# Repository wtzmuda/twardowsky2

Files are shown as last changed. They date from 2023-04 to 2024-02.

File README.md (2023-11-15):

<div align="center">
    

  <h3 align="center"><strong>Twardowsky 2</strong><br/>SKA Rocketry Division</h3>

  <p align="center">
      <a href="https://wutwaw-my.sharepoint.com/:f:/g/personal/01171578_pw_edu_pl/EmQTOotIGo9FmwbVG2P4nIABuc8mOalsro14rPONq2J7Fg" target="_blank"><strong>See project's sharepoint »</strong></a>
    <br />
    <br />
    <a href="https://gitlab.com/sekcja-rakietowa-ska/twardowsky2/-/commits/main?ref_type=heads">Commits</a>
    ·
    <a href="https://gitlab.com/sekcja-rakietowa-ska/twardowsky2/-/branches">Branches</a>
    ·
    <a href="https://gitlab.com/sekcja-rakietowa-ska/twardowsky2/-/issues">Issues</a>
  </p>
</div>

## Getting started

Run `git clone https://gitlab.com/sekcja-rakietowa-ska/twardowsky2.git`

*Do not have a git? Ask our coordinator for help!*

Remember to run `RunThisWhenYouClone.sh` command after cloning this repository. This makes sure that Your commit messages are correctly formatted and up to our standards.

Also we have strict messaging and naming standards. Please read *Git messages standards* section .

## Project description

Twardowsky 2 is a hybrid-engine rocket with ability to carry payload in the form of cubesat experiments. It is being developed by the Student's Space Association's Rocketry Division on Warsaw University of Technology.

## Git messages standards

Correct formmat for our messages is:
`[TAG] commit-message` or `#issue-number commit-message`

Where: 
* **TAG** - Points out which system does this commit concern? 
* **#issue-number** - Points out which issue does this commit concern?
* **commit-message** - Is a description of the changes. Remember it is not ught to be short. It should be as descriptive and precise as it can be.

*Example: [PLD] Changed strings on payload's module.*

### Commit tags
Below are listed possible tags with it's description:

* **[TWR]** - Twardowsky - concerning whole project (like req / risk changes), can be used with other tags to specify but there are files that concern the whole project
* **[GSG]** - Ground segment - concerning GSE, mission control, procedures for launches etc.
* **[SPC]** - Spacecraft - technical changes to TWR assembly
* **[NSC]** - Nosecone
* **[PLD]** - Payload
* **[REC]** - Recovery
* **[PRP]** - Propulsion
* **[AVI]** - Avionics (I know seems kinda redundant since we have NSC but there are SE aspects that could concern only Avionics)
* **[CTS]** - COTS/standardized elements changes
* **[MNG]** - Management / organizational
* **[DOC]** - Documentation
* **[SYS]** - Systems engineering
* **[OTH]** - doesn't fit any of the above (might suggest that there's need for new tag)

*Feel free to contact Your coordinator if You have any doubts or remarks.*

### Commit issues
Below are listed possible issues with it's description: 

* **#1** - Construction/mechanical/technical
* **#2** - Electronics/software/firmware
* **#3** - Documentation
* **#4** - Systems Engineering
* **#5** - Analysis
* **#6** - Management/administration
* **#7** - Finances/orders
* **#8** - Competitions
* **#9** - Research
* **#10** - Other

## Contact

1. **Project coordinator** - Eliza Łapińska - yes sir#1909

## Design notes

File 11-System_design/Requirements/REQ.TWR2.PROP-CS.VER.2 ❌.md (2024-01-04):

---
Title: REQ.TWR2.PROP-CS.VER.2
Status: conflict
System: TWR2.PROP-CS
Class: Requirement
Conflicting With: 11-System_design/Requirements/REQ.TWR2.PROP-CS.VER.1 ❌.md
---

## Description

During leakage test conditions (8 bar for 180 minutes) the maximum allowable pressure drop is less than 0.5 bar

## Source

TWR 2 propulsion

NO - [The requirements do not conflict because they pertain to different testing conditions and pressures. The first requirement refers to a leakage test at 8 bar, the second to a pressure proof test at 90 bar, and the third to a filling and pressurization procedure at a max of 60 bar. Each requirement has the same allowable pressure drop of less than 0.5 bar, but this value is not in conflict across the different conditions and pressures.]YES - There is a conflict between the given leakage test condition and the proof pressure test conditions as well as the condition regarding the tank pressurization. The pressure for the proof test condition and tank pressurization is significantly higher than the given leakage test condition. This may result in different maximum allowable pressure drops, leading to potential conflicts - [[11-System_design/Requirements/REQ.TWR2.PROP-CS.VER.1 ❌.md]], [[Requirements/REQ.TWR2.AVI.DES.33  ❌.md]]. To resolve the issue, it would be better to harmonize and clearly define the pressure conditions and allowable pressure drops across all tests.YES - The first and third requirements specified different pressure and time conditions for a test, causing a conflict - [[11-System_design/Requirements/REQ.TWR2.PROP-CS.VER.1 ❌.md]], [[undefined]]. A better way to resolve it would be to standardize the conditions for the pressure test and define it in one requirement.

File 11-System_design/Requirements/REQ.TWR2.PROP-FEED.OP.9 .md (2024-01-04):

---
Title: REQ.TWR2.PROP-FEED.OP.9
Status: in-review
System: TWR2.PROP-FEED
Class: Requirement
Conflicting With: 
---

## Description

Sealants of hydraulic systems shall allow to conduct the procedure of filling and pressurizing (max duration 90 minutes at max pressure 60 bar) with acceptable pressure drop of 0,5 bar 

## Source

TWR 2 propulsion/ REQ.TWR2.PROP.OP.6

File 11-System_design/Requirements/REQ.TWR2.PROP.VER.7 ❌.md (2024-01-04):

---
Title: REQ.TWR2.PROP.VER.7
Status: conflict
System: TWR2.PROP
Class: Requirement
Conflicting With: 11-System_design/Requirements/REQ.TWR2.PROP-CS.VER.2 .md
---

## Description

Pressure vessels shall be proof pressure tested successfully to 1.5 times the maximum expected operating pressure for no less than twice the maximum expected system working time, using the intended flight components. The maximum system working time is defined as the maximum uninterrupted time duration the vessel will remain pressurized during pre-launch, flight, and recovery operations. 

## Source

EuRoC/ IREC Design, Test, & Evaluation Guide 2023 V1.3/ 6.25.1., 6.25.2.- Bartosz Hyży

undefined

undefined

undefinedYES - The given requirement states that pressure vessels should be tested successfully to 1.5 times the maximum expected pressure for a duration that is twice the maximum expected system working time. However, in REQ.TWR2.PROP-CS.VER.2 the condition for leakage tests is given as 8 bar for 180 minutes. There may be a conflict if the maximum expected operating pressure multiplied by 1.5 or the maximum expected system working time doubled does not match the 8 bar for 180 minutes condition. Depending on the actual maximum expected operating pressure and system working time, these conditions might not align. - [[REQ.TWR2.PROP-CS.VER.2 ]]

A possible resolution can be standardizing the testing conditions across all documents, or explaining how both these tests have different objectives and should be executed separately.YES - The given requirement demands a proof pressure test at 1.5 times the maximum expected operating pressure and for a time duration twice that of the maximum expected system working time. Yet, the requirement to compare specifies testing for leakage conditions at a defined pressure (8 bar) for 180 minutes. These two testing conditions may not be the same and thus, a conflict arises. A possible solution would be to harmonize the testing conditions such that the proof pressure test and the leakage test can both be conducted without contradicting each other. - [[REQ.TWR2.PROP-CS.VER.2 ]]

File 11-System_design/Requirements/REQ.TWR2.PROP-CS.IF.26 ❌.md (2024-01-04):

---
Title: REQ.TWR2.PROP-CS.IF.26
Status: conflict
System: TWR2.PROP-CS
Class: Requirement
Conflicting With: 11-System_design/Requirements/REQ.TWR2.PROP-CS.CONF.19 .md
---

## Description

It shall be possible to install swirl injector or showerhead injector in the same plug assembly

## Source

TWR 2 propulsion

undefined

undefined

undefined

undefined

undefined

undefinedYES - There are potential conflicts between the requirement of having both a swirl injector or showerhead injector in the same plug assembly and the requirement that an igniter be located in the plug assembly. Depending on the arrangement, there might not be enough space in the assembly for both an injector and an igniter. Also, the requirement concerning the showerhead injector hole diameter assumes a specific design that may or may not be compatible with the use of an igniter or swirl injector. [[11-System_design/Requirements/REQ.TWR2.PROP-CS.CONF.19 .md]] [[11-System_design/Requirements/REQ.TWR2.PROP-CS.PHYS.22 .md]]

A possible solution could involve designing the plug assembly to accommodate different configurations or clarify the design constraints of the showerhead injector and swirl injector so they can coexist with the igniter. Another possibility could be to revise the requirement about the igniter's location.YES - The requirement specifies two types of injectors to be installed in the plug assembly, however, there is another requirement for the igniter to be located in the same assembly. This can create a space conflict within the plug assembly. It needs to be ensured that the igniter and either of the injectors can be fitted into the plug assembly without any functional obstruction - [[11-System_design/Requirements/REQ.TWR2.PROP-CS.CONF.19 .md]]

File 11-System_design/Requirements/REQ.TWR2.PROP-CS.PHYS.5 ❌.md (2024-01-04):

---
Title: REQ.TWR2.PROP-CS.PHYS.5
Status: conflict
System: TWR2.PROP-CS
Class: Requirement
Conflicting With: 11-System_design/Requirements/REQ.TWR2.PROP-CS.PHYS.4 .md
---

## Description

Combustion chamber insulation shall allow the combustion chamber hardware to withstand temperature loads (3300K) for the time of work (10s)

## Source

TWR 2 propulsion

NO - [There doesn't appear to be any conflicts between these requirements. The given requirement pertains to temperature loads and duration, the first requirement to compare speaks to mechanical loads, the second one refers to pressure and duration, and the third one addresses testing. These specifications are dealing with different aspects of the combustion chamber's functionality and should not conflict unless specific material, design or procedures counteract.]YES - The time of work given in the first compared requirement (20s) contradicts with the time of work given in the given requirement (10s). - [[11-System_design/Requirements/REQ.TWR2.PROP-CS.PHYS.4 .md]] 

One possible way to resolve this issue might be adjusting one of the time frames to match with the other one after considering engineering constraints and the overall mission goals.YES - The given requirement and the first compared requirement may conflict. The given requirement suggests the chamber will operate at 3300K for 10 seconds, but the compared requirement states that the chamber needs to withstand a pressure of 45 bar for 20 seconds. If the chamber can only endure high temperatures for half of the required pressure duration, this could result in damage or failure. - [[11-System_design/Requirements/REQ.TWR2.PROP-CS.PHYS.4 .md]]

To resolve the issue, we should aim to improve the insulation of the combustion chamber or redesign it so that the temperature can be maintained for a longer duration. This might involve using different materials for insulation or altering the combustion chamber's design to dissipate heat more effectively.

[[11-System_design/Requirements/REQ.TWR2.PROP-CS.PHYS.4 .md]] should be updated to make sure both conditions (temperature and pressure) can be sustained for the same duration.

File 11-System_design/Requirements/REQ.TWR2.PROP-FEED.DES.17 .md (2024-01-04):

---
Title: REQ.TWR2.PROP-FEED.DES.17
Status: in-review
System: TWR2.PROP-FEED
Class: Requirement
Conflicting With: 
---

## Description

Main valve shall incorporate at least two redundant pyrotechnic primes

## Source

TWR 2 propulsion

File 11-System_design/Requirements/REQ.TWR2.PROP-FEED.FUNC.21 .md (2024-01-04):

---
Title: REQ.TWR2.PROP-FEED.FUNC.21
Status: in-review
System: TWR2.PROP-FEED
Class: Requirement
Conflicting With: 
---

## Description

The venting system should ensure a reliable release of oxidizer outside the rocket structure in the event of launch abort

## Source

#REF!

undefined

undefined

undefined

undefined

undefined

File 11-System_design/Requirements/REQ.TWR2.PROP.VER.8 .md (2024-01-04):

---
Title: REQ.TWR2.PROP.VER.8
Status: in-review
System: TWR2.PROP
Class: Requirement
Conflicting With: 
---

## Description

Propulsion systems shall successfully complete an instrumented (chamber pressure and/or thrust), full scale (including system working time) static hot-fire test. The test shall be conducted under the most realistic settings possible. Test results from horizontal tests, using flight components, are less optimum, whereas test results from test benches (not using flight components) do not qualify. (TBD with EuRoC)

## Source

EuRoC

undefined

undefined

undefined

undefined

undefined

undefined

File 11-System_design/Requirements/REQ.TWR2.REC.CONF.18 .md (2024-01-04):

---
Title: REQ.TWR2.REC.CONF.18
Status: in-review
System: TWR2.REC
Class: Requirement
Conflicting With: 
---

## Description

All safety critical wiring shall implement a cable management solution (e.g., wire
ties, wiring, harnesses, cable raceways) which will prevent tangling and excessive
free movement of significant wiring/cable lengths due to expected launch loads.  Wiring shall be labeled or color-coded to allow easy determination of the subsystem
to which it is attached. 

## Source

Spaceport: IREC Design, Test, & Evaluation Guide 2023 V1.3/ 5.7.1. -Szymon Życiński

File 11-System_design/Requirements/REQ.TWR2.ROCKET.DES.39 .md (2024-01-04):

---
Title: REQ.TWR2.ROCKET.DES.39
Status: in-review
System: TWR2.ROCKET
Class: Requirement
Conflicting With: 
---

## Description

PVC (and similar low-temperature polymers), Public Missiles Ltd. (PML) Quantum Tube,
and stainless-steel shall not be used in any rocket airframe structure. PVC (and similar lowtemperature polymers), stainless steel, or other frangible materials shall not be used for a solid or hybrid propulsion system combustion chamber. 

## Source

 Spaceport: IREC Design, Test, & Evaluation Guide 2023 V1.3/ 8.3.- Bartosz Hyży

undefined

undefined

undefined

undefined

undefined

undefined

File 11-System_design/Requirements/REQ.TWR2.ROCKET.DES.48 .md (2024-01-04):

---
Title: REQ.TWR2.ROCKET.DES.48
Status: in-review
System: TWR2.ROCKET
Class: Requirement
Conflicting With: 
---

## Description

Airframe joints which implement "coupling tubes" should be designed such that the coupling tube extends no less than one body calibre (1D) on either side of the joint — measured from the separation plane. This rule applies both for “half” couplings (e.g., nosecone – body tube/coupling tube) as well as for “full” couplings (e.g., body tube – coupling tube – body tube)

## Source

EuRoC Design, Test & Evaluation Guide; Version 4.4

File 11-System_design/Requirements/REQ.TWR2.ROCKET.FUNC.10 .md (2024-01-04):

---
Title: REQ.TWR2.ROCKET.FUNC.10
Status: in-review
System: TWR2.ROCKET
Class: Requirement
Conflicting With: 
---

## Description

The rocket's subsystems shall have an ability to function independetly, their joints shall be standardized and they shoud be exchangeable.

## Source

Concept of Operation/ Eliza Łapińska

undefined

undefined

undefined

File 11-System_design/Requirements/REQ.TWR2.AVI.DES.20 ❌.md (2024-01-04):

---
Title: REQ.TWR2.AVI.DES.20
Status: conflict
System: TWR2.AVI
Class:
  - Requirement
ID: TWR2.AVI.REQ.TWR2.AVI.DES.20
Conflicting With: 11-System_design/Requirements/REQ.TWR2.AVI.DES.39 ❌.md
---

## Description
RF transmitter, receivers or transceivers are not allowed to be mounted externally. Any RF antenna should have either: "RF Window" for antennas mounted internally or at least two-sided antenna mounted externally to provide for full 360 coverage. [NOTE] Single antenna mounted on the rear-fin of a flight vehicle will be insufficient, since the exhaust flames are highly disruptive towards the RF signals

## Source

EuRoC Design, Test & Evaluation Guide; Version 4.6

# Conflict

YES - The conflict lies in the location of RF transmitters, receivers or transceivers, and antennas; the given requirement mandates no external mountings, whereas the requirement in comparison implies the possibility of such installations. - [[11-System_design/Requirements/REQ.TWR2.AVI.DES.39 ❌.md]] 
A possible resolution would be to agree upon fixed locations for the RF devices and the antennas, either internally with RF windows or externally considering the "360 deg" coverage rule.

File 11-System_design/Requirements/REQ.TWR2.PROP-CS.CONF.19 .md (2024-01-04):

---
Title: REQ.TWR2.PROP-CS.CONF.19
Status: in-review
System: TWR2.PROP-CS
Class: Requirement
Conflicting With: 
---

## Description

Igniter should be located in the plug assembly

## Source

TWR 2 propulsion

undefined

undefined

undefined

undefined

undefined

undefined

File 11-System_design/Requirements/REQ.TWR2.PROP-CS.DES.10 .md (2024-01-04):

---
Title: REQ.TWR2.PROP-CS.DES.10
Status: in-review
System: TWR2.PROP-CS
Class: Requirement
Conflicting With: 
---

## Description

Combustion chamber geometry shall allow stable work of engine (precombustion chamber)

## Source

TWR 2 propulsion

NO - [The requirements do not in-revision each other. The given requirement and others all deal with various aspects of the combustion chamber such as its functionality, ability to conduct tests, sealing under pressure, and integration with the rest of the rocket. None of these aspects are mutually exclusive or contradictory, which means all these requirements can be fulfilled without conflicting with each other.]

NO - All of the requirements listed are related to the quality, functionality, and compatibility of the combustion chamber. They should not conflict since each one addresses a different aspect of the design. Stable operation, integration with the rocket, and ability to undergo pressure tests do not inherently conflict.

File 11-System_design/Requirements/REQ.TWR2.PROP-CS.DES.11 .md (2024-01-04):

---
Title: REQ.TWR2.PROP-CS.DES.11
Status: in-review
System: TWR2.PROP-CS
Class: Requirement
Conflicting With: 
---

## Description

Combustion chamber geometry shall allow the Hot Fire test on Hefajstos test stand

## Source

TWR 2 propulsion

NO - [There is no direct conflict between the given requirement and the requirements to compare. The ability to conduct a Hot Fire test on a Hefajstos test stand does not inherently conflict with the needs for the combustion chamber to allow pressure and seal tests, to work stably, to be integrable with the rocket, or to withstand mechanical loads during flight. These requirements are all addressing different facets of the combustion chamber’s functionality and integrity. However, the satisfaction of all requirements would need to be validated empirically.]

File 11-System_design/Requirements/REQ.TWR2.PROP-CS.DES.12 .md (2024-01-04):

---
Title: REQ.TWR2.PROP-CS.DES.12
Status: in-review
System: TWR2.PROP-CS
Class: Requirement
Conflicting With: 
---

## Description

There shall be appropriate sealing elements placed to inhibit outer surface of grain

## Source

TWR 2 propulsion- Bartek Hyży

undefined

undefined

undefined

undefined

undefined

undefined

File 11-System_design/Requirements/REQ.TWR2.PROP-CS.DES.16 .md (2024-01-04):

---
Title: REQ.TWR2.PROP-CS.DES.16
Status: in-review
System: TWR2.PROP-CS
Class: Requirement
Conflicting With: 
---

## Description

 All teams shall use dual or dual-headed motor igniters for launch

## Source

Spaceport: IREC Design, Test, & Evaluation Guide 2023 V1.3/ 5.9.- Bartosz Hyży

undefined

NO - The requirement to compare is identical to the given requirement, therefore there are no in-revisions.

undefined

undefined

undefined

undefined

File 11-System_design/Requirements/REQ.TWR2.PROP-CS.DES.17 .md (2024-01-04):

---
Title: REQ.TWR2.PROP-CS.DES.17
Status: in-review
System: TWR2.PROP-CS
Class: Requirement
Conflicting With: 
---

## Description

Igniter's sealings shall be made from materials compatible with nitrous oxide

## Source

TWR 2 propulsion

NO - [All the compared requirements specify the materials to be compatible with nitrous oxide or corrosion-resistant, this does not conflict with the given requirement which also states the materials used should be compatible with nitrous oxide.]

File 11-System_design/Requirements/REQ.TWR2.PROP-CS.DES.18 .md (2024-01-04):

---
Title: REQ.TWR2.PROP-CS.DES.18
Status: in-review
System: TWR2.PROP-CS
Class: Requirement
Conflicting With: 
---

## Description

Igniter shall use black powder as the main propellant

## Source

TWR 2 propulsion

undefined

undefined

undefined

undefined

undefined

undefined

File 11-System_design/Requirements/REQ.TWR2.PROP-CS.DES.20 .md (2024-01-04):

---
Title: REQ.TWR2.PROP-CS.DES.20
Status: in-review
System: TWR2.PROP-CS
Class: Requirement
Conflicting With: 
---

## Description

Igniter shall be made from materials that are corrosion resistant or are corrosion protected

## Source

TWR 2 propulsion

NO - [The given requirement specifies that the igniter should be made from materials that are either corrosion-resistant or protected against corrosion. The other requirements state that the igniter body and sealings should be made from materials compatible with nitrous oxide and that the injection system elements should be corrosion-resistant. None of these requirements conflict with each other, because it's possible for a material to be both corrosion-resistant and compatible with nitrous oxide. Hence, there are no conflicts between these requirements.]

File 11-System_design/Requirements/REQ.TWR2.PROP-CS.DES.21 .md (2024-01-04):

---
Title: REQ.TWR2.PROP-CS.DES.21
Status: in-review
System: TWR2.PROP-CS
Class: Requirement
Conflicting With: 
---

## Description

Igniter body shall be made from materials compatible with nitrous oxide

## Source

TWR 2 propulsion

NO - [The given requirement states that the igniter body should be made from materials compatible with nitrous oxide. This is consistent with all the compared requirements, which either specifically mention nitrous oxide compatibility (the igniter sealings, injection system, and contact components) or suggest a condition (corrosion resistance/protection) that does not inherently conflict with nitrous oxide compatibility. Therefore, there are no conflicts between these requirements.]

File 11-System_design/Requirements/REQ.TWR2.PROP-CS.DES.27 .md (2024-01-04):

---
Title: REQ.TWR2.PROP-CS.DES.27
Status: in-review
System: TWR2.PROP-CS
Class: Requirement
Conflicting With: 
---

## Description

Injection system elements hall be made from materials compatible with nitrous oxide

## Source

TWR 2 propulsion

NO - [All the requirements state that the specific components of the system need to be compatible with nitrous oxide. Additionally, the requirement that injection system elements shall be made from corrosion resistant materials does not in-revision with the given requirement, as corrosion-resistant materials could still be compatible with nitrous oxide. Therefore, there is no conflict between the stated requirements.]

NO - [All requirements state that the materials used in the injection system should be compatible with nitrous oxide. There is another requirement that the materials should also be corrosion resistant. There is no conflict between these requirements, unless a material that is compatible with nitrous oxide is not corrosion resistant. However, this is not specified, so no conflict can be determined based on the information provided.]

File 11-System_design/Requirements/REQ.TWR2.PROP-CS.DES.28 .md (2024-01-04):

---
Title: REQ.TWR2.PROP-CS.DES.28
Status: in-review
System: TWR2.PROP-CS
Class: Requirement
Conflicting With: 
---

## Description

Injection system elements shall be made from corrosion resistant materials

## Source

TWR 2 propulsion

NO - [The materials for the injection system elements can be both corrosion resistant and compatible with nitrous oxide; these requirements are not mutually exclusive. Also, the second comparison requirement simply specifies that the igniter should be corrosion resistant or protected, which does not contradict the given requirement.]

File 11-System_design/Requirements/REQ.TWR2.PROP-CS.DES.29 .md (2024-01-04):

---
Title: REQ.TWR2.PROP-CS.DES.29
Status: in-review
System: TWR2.PROP-CS
Class: Requirement
Conflicting With: 
---

## Description

Materials of the sealings in injection system shall be compatible with nitrous oxide

## Source

TWR 2 propulsion

NO - [All requirements mandate that materials in contact with nitrous oxide, including sealings, be compatible with it. Therefore, there is no conflict among these requirements. All are in sync, working towards ensuring suitability and safety with nitrous oxide.]

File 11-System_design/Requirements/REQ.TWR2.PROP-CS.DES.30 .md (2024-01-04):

---
Title: REQ.TWR2.PROP-CS.DES.30
Status: in-review
System: TWR2.PROP-CS
Class: Requirement
Conflicting With: 
---

## Description

The nozzle geometry should allow usage of appropriate nozzle plug to gain the initial pressure of work (10 bar)

## Source

TWR 2 propulsion

undefined

undefined

undefined

undefined

undefined

undefined

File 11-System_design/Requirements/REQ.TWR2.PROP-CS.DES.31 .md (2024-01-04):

---
Title: REQ.TWR2.PROP-CS.DES.31
Status: in-review
System: TWR2.PROP-CS
Class: Requirement
Conflicting With: 
---

## Description

Nozzle shall allow satisfying (without risk of combustion products overexpansion) flow of combustion products (nozzle throat diameter and exit diameter)

## Source

TWR 2 propulsion- Bartek Hyży

undefined

undefined

undefined

undefined

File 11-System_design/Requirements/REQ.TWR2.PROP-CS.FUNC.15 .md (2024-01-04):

---
Title: REQ.TWR2.PROP-CS.FUNC.15
Status: in-review
System: TWR2.PROP-CS
Class: Requirement
Conflicting With: 
---

## Description

Igniter construction should maximize heat trasfer between igniter hot products and grain surface

## Source

TWR 2 propulsion

undefined

undefined

undefined

undefined

undefined

undefined

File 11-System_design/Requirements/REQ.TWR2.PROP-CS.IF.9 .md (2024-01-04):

---
Title: REQ.TWR2.PROP-CS.IF.9
Status: in-review
System: TWR2.PROP-CS
Class: Requirement
Conflicting With: 
---

## Description

Combustion chamber shall be integrable with the rest of the rocket

## Source

TWR 2 propulsion

NO - All the compared requirements pertain to the manufacturing, functioning, and testing of the combustion chamber, and none of them seem to conflict with the requirement that the combustion chamber shall be integrable with the rest of the rocket. In fact, these requirements seem to support the integration of the combustion chamber with the rest of the rocket by ensuring that it is properly manufactured, can function stably, can withstand mechanical loads, and can undergo necessary tests.

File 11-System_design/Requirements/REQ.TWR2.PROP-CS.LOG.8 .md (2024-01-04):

---
Title: REQ.TWR2.PROP-CS.LOG.8
Status: in-review
System: TWR2.PROP-CS
Class: Requirement
Conflicting With: 
---

## Description

Combustion chamber body should be manufacturable in our workshop

## Source

TWR 2 propulsion

NO - [None of the compared requirements inherently conflict with the ability to manufacture the combustion chamber within your workshop. The ability to manufacture locally often concerns the available materials, tools, and skills. The requirements listed involve the functional specifications of the design and do not specify a manufacturing process that might not be achievable in the workshop. Therefore, as long as the workshop is equipped and skilled to produce the specified design, there should not be any conflicts.]

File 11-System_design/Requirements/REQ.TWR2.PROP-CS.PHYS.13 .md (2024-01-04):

---
Title: REQ.TWR2.PROP-CS.PHYS.13
Status: in-review
System: TWR2.PROP-CS
Class: Requirement
Conflicting With: 
---

## Description

Maximum pressure created by the igniter shall be less than 75% of working pressure

## Source

TWR 2 propulsion

undefined

undefined

undefined

undefined

undefined

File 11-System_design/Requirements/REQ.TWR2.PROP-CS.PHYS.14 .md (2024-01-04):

---
Title: REQ.TWR2.PROP-CS.PHYS.14
Status: in-review
System: TWR2.PROP-CS
Class: Requirement
Conflicting With: 
---

## Description

Igniter shall generatere reapitable pressure curve wihch shall be understood as getting pressure curve with +/- 0.5 bar mistake 3 times in a row.

## Source

TWR 2 propulsion

undefined

undefined

undefined

undefined

undefined

undefined

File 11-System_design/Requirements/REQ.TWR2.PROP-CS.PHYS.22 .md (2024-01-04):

---
Title: REQ.TWR2.PROP-CS.PHYS.22
Status: in-review
System: TWR2.PROP-CS
Class: Requirement
Conflicting With: 
---

## Description

In case of use showerhead injector - hole diameter should be less than 1.5 mm

## Source

TWR 2 propulsion

undefined

undefined

undefined

undefined

undefined

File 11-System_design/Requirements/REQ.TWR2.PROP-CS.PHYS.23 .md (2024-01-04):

---
Title: REQ.TWR2.PROP-CS.PHYS.23
Status: in-review
System: TWR2.PROP-CS
Class: Requirement
Conflicting With: 
---

## Description

Calculated injecton half angle shall be within the range 20 - 60° (in case of using swirl injector)

## Source

TWR 2 propulsion

undefined

undefined

undefined

undefined

undefined

undefined

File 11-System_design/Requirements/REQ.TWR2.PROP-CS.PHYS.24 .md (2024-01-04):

---
Title: REQ.TWR2.PROP-CS.PHYS.24
Status: in-review
System: TWR2.PROP-CS
Class: Requirement
Conflicting With: 
---

## Description

Calculated Sauter Mean Diameter shall be within the range 20-100 micrometers (in case of using swirl injector)

## Source

TWR 2 propulsion

undefined

undefined

undefined

undefined

undefined

undefined

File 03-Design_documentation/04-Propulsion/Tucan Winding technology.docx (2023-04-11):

New TuCAN Winding Technology

Prepared by:

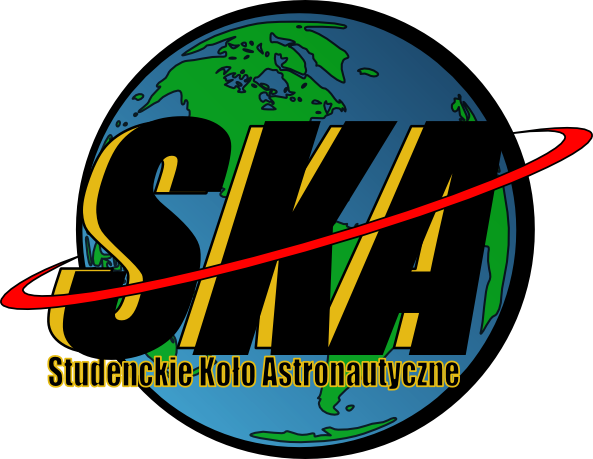
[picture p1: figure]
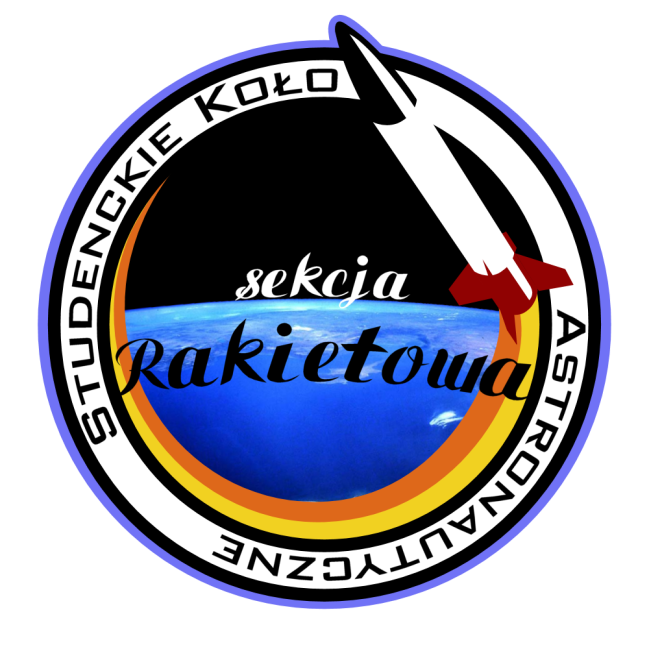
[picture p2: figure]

Nezar Sahbon

Vinicius Ferreira

Warszawa, November 2019

3 System Description.................................................................................6

## 3.1 Core Tube(NWST.1.00.00.001_core_tube)

## 3.2 Fix support holder (NWST.1.00.00.003_Support_fix_holder)

## 3.3 Support plate (NWST.1.00.00.004_Support_plate)

3.4 Brass ring (NWST.1.02.00.001_Brass_ring)

## 3.5 Pressure exerting subsystem

4 New engine production process – instruction

4.1 Introduction

4.2 Instructions

5 Summary

Introduction

This document presents the description, analysis and instructions for using the new production technology of composite rocket engines with an internal diameter of 122mm (class TuCAN).

# 1 Genesis

## 1.1 Old technology and its disadvantages

The previous production process was as follows: on a properly prepared shaft or pipe with an outer diameter (to be specified), two inserts were applied at a distance of (to be specified) from each other. The previously prepared Carbon Fibres fabric was Winded on it while applying resin as it rolls. Then the whole system went to the Oven. After that, with the help of a Dismantling system in the means of a puller deivce, the body was separated from the shaft. During this process, there were several obstacles ,mainly concerning the product which is the result of the system but not the system itself,having the bigger diameter on the casing as a concequence of using the inserts,necessity to machine the insulation to fit it to a particular casing by our own,the need to use heavy machinary to move the insulation inside the casing as well as winding a single fiber on a spool

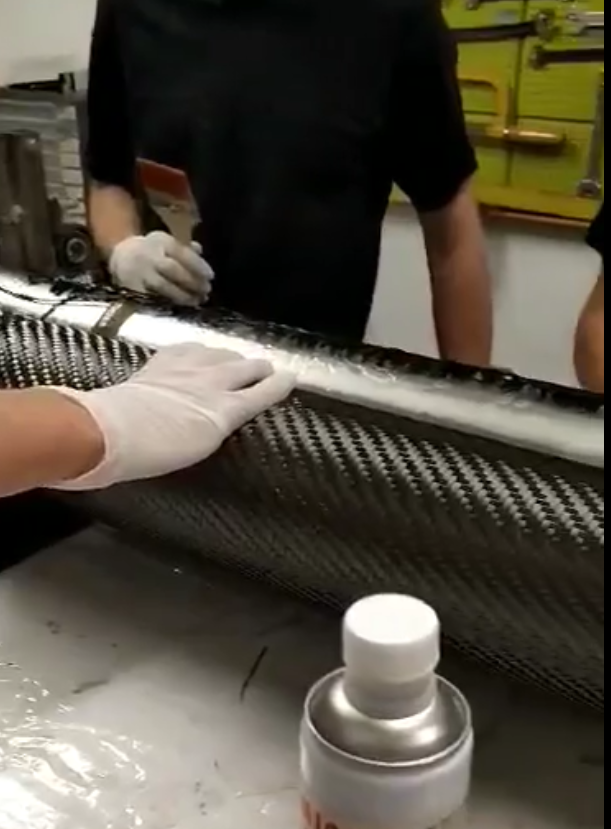
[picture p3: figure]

Figure 1.1 Old Winding technology for composite casing

## 1.2 Motivation

In order to eliminate these problems and have a successful operations of the new engine after the production process such as hydrotests, assembling the entire engine before static tests and flights, as well as the need for direct winding, there was a need to develop a system that allows winding with the use of inserts with different design than their predecessor allowing us to gain ideal fitting between insulation and casing, without thed need to adjust the insulation to casing or move it in any way.

# 2. Solution

In order to achieve the objective of our system, we have to change the design of our system in a way which enables us direct winding on the insulation with inserts on the core. Hence the proposal to use a simillar core tube but with slightly different parameters with two fixed Lids of diameter 102mm (inner diameter of the body), as well as fixing the position of insulation with inserts on the core. The advantages of this option are: The new system is insusceptible to variations of the outer diameter of the insulation and allows us to fit perfectly for it’s length, resistant to water absorption during hydro tests due to no need of moving the insulation inside casing, constant Winding of the fabric with the need of only two single fiber wounds on both ends instead of four, while the disadvantages: Assembling the system will be slightly more difficult than the provious system, which makes the system slightly more complicated and thus more expensive.

# 3 System Description

Elements of the new system for the production of the TuCAN class engine are: Coretube(shaft), 2x Lid M20, 2x support fix holder, 2x support plate, pressure tube, Module rings, Brass ring, 8x M10 screws, 4x M20 screws, 16x M8 screws.

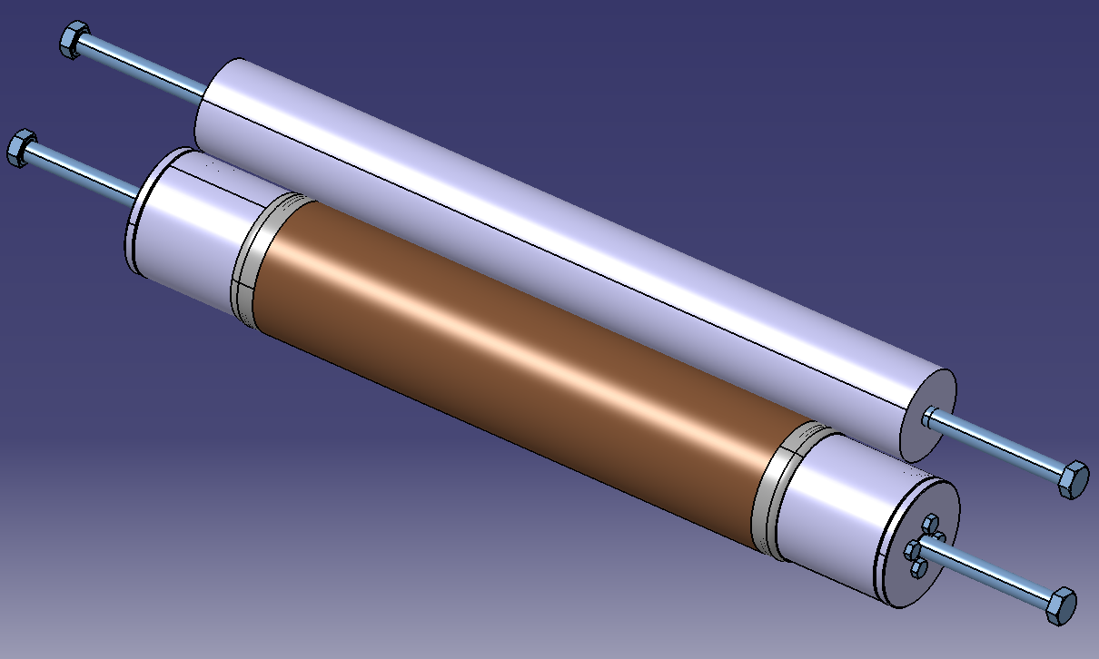
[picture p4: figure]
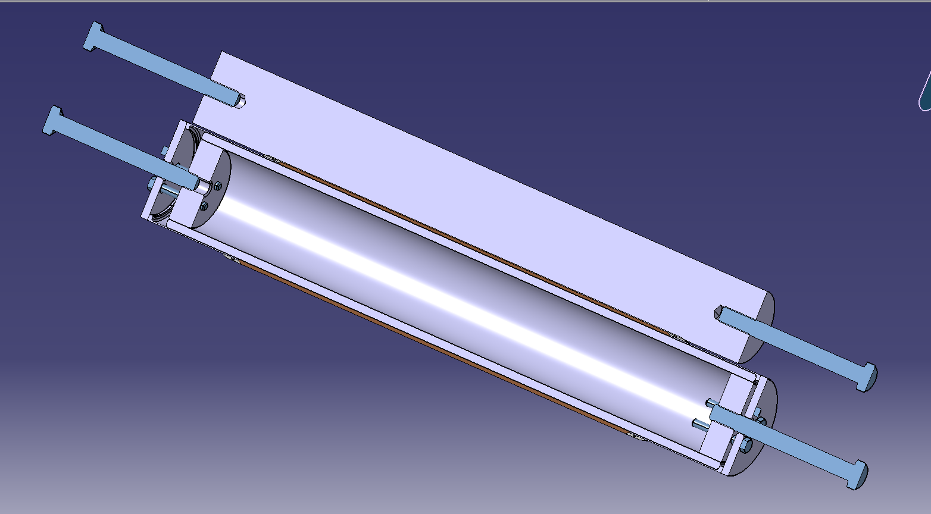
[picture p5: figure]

## 1.3 Core Tube(NWST.1.00.00.001_core_tube)

The Core tube acts as the roller shaft of the entire system, it ensures stability, keeps all the other parts in place as well as enabling a smooth and proper winding of the fabric. The contact between the the shaft and the resin is very minimal thanks to the fact the laminate has no direct touch to the shaft, our shaft is made from Stainless steel which ensures chemical and mechanical strength and it is relatively easy to work with.

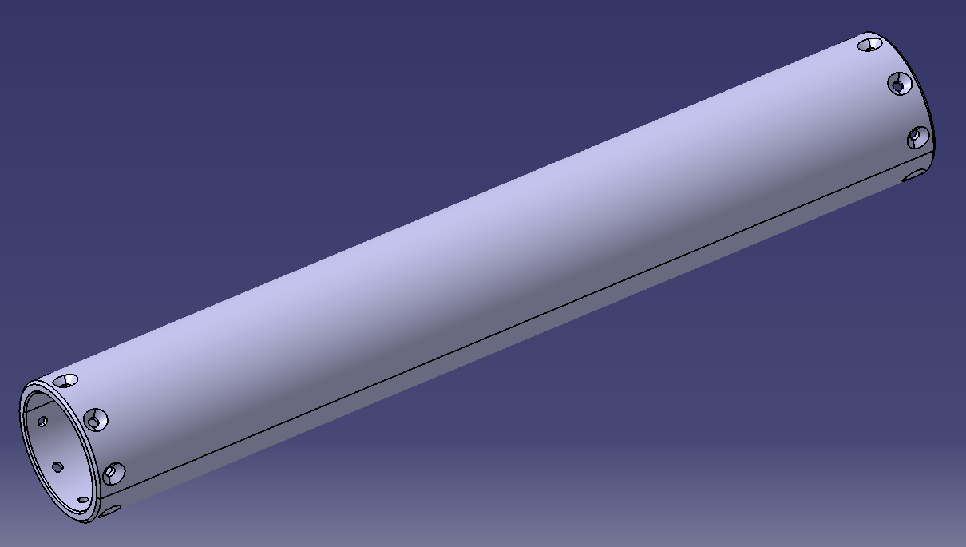
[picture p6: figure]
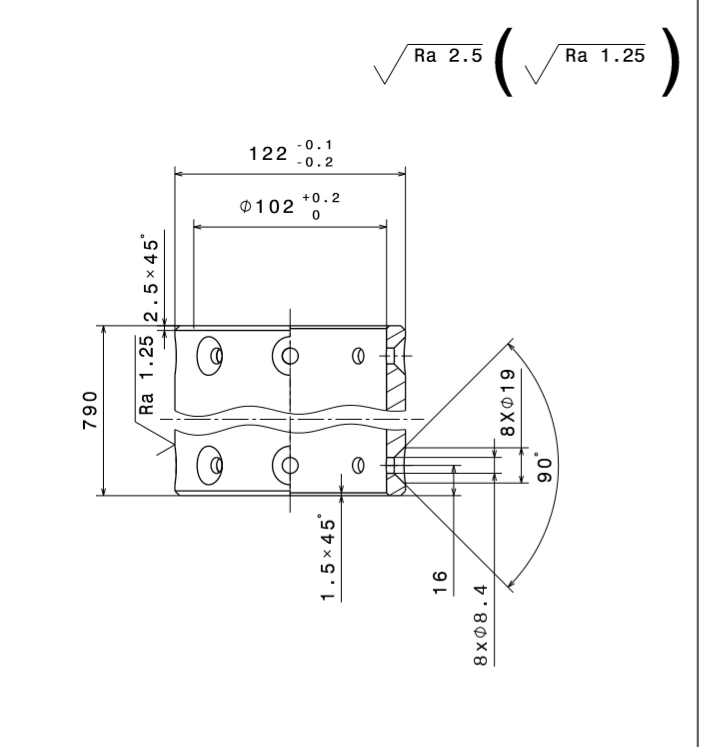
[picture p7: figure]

## 1.4 Fix support holder (NWST.1.00.00.003_Support_fix_holder)

Fix support holder’s objective is to keep a steady grip of the insulation using the force produced by the M10 screws connecting the support plate with the M20 Lid.

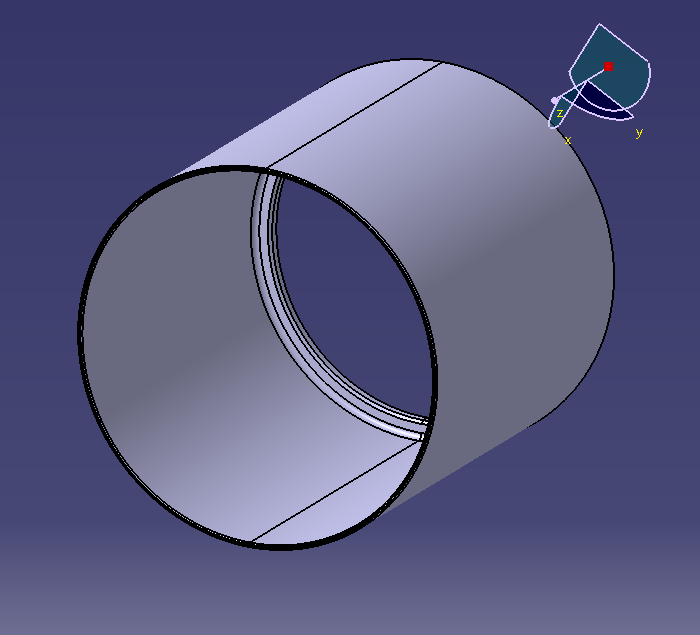
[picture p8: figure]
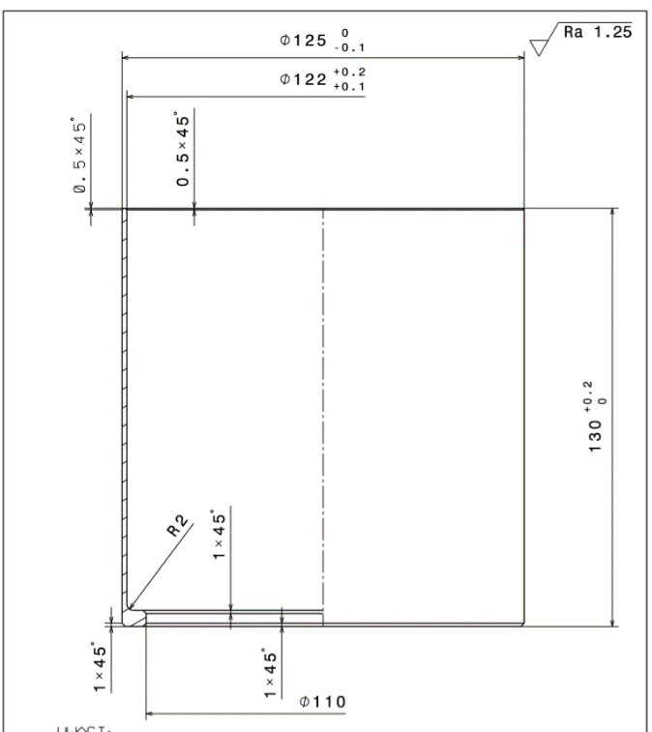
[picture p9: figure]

## 1.5 Support plate (NWST.1.00.00.004_Support_plate)

The design of the support plate allows us to pin the support fix holder by connecting it with the M20 Lid using the M10 screws.

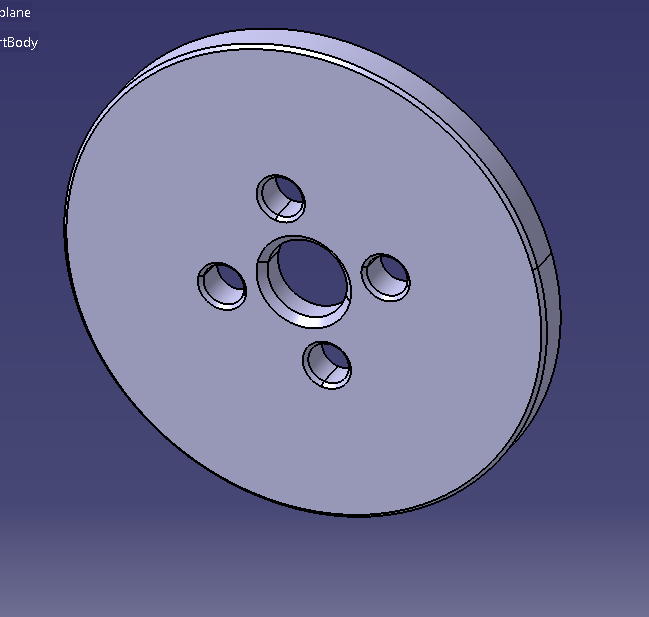
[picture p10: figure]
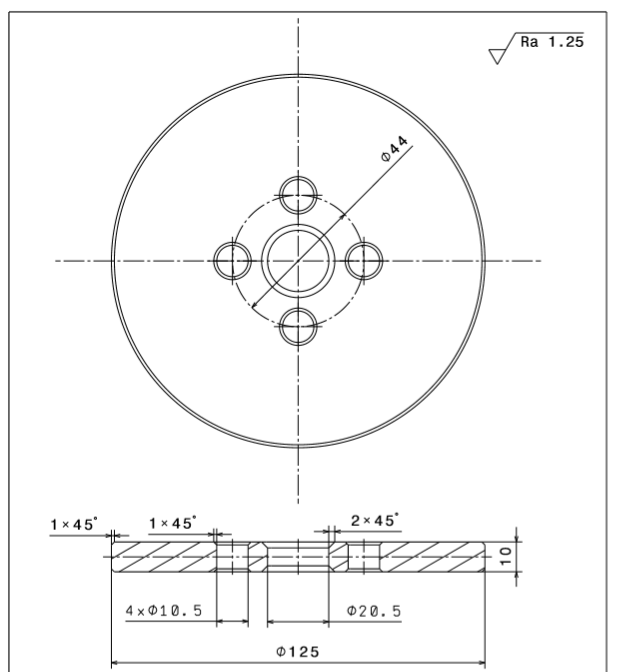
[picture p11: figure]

## 3.4 Brass ring (NWST.1.02.00.001_Brass_ring)

Another part of our dismantling support will be the brass ring which is also designed in a way that the outer diameter is greater than the SR puller which allows us easy extraction of the engine.

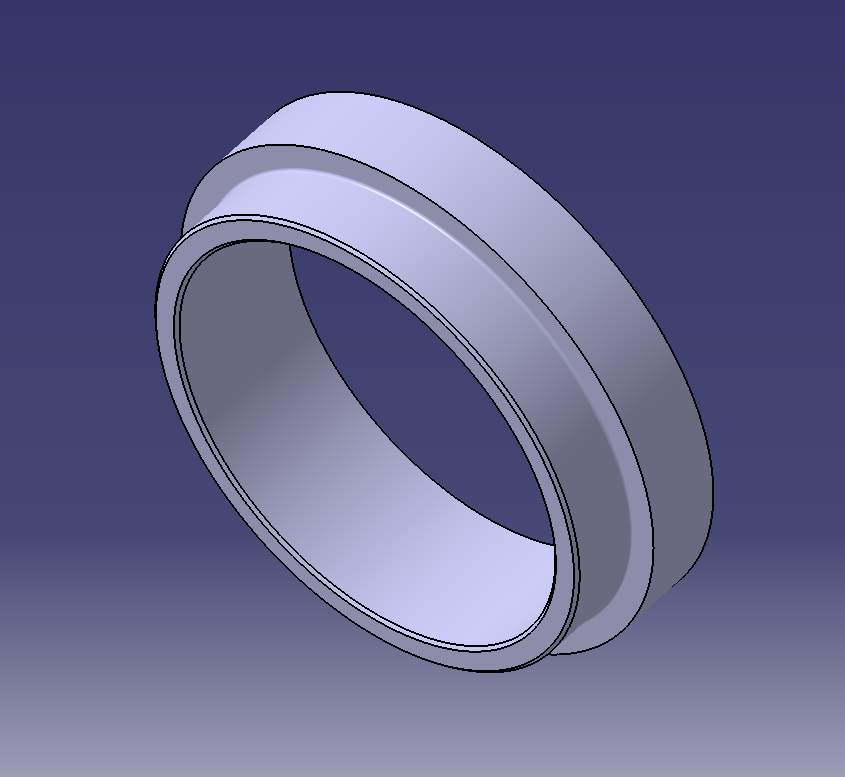
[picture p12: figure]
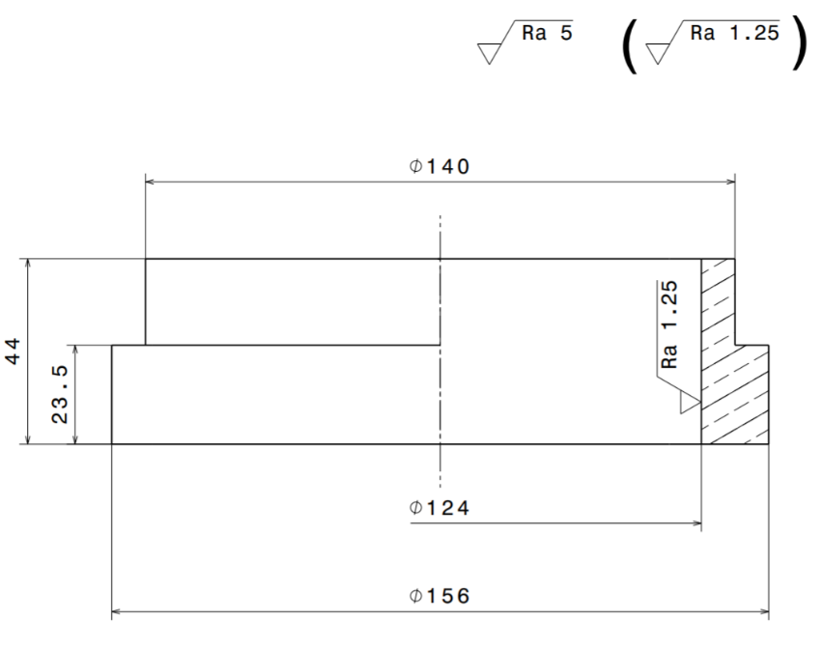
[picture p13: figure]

## 3.5 Pressure exerting subsystem

Our pressure subsystem consists of one main tube, due to the fact that we have just one tube in our subsystem, the consequences will be a heavier subsystem, we chose the material to be stainless steel due to it’s chemical and mechanical strength, lastly we will have two module rings to keep the entire system in contact with our core tube(main shaft).

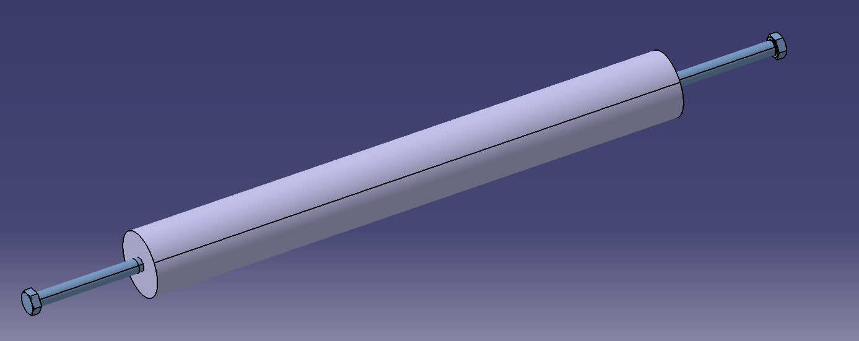
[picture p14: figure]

# 4 New engine production process – instruction

## 4.1 Introduction

Before reading the following instructions, it is recommended to read: Instructions for making composite engine bodies TuCAN, because it is based on this document and presents changes in comparison with the old process rather than a full-fledged instructions for making the engine with new technology.

Note: Before starting the production procedure make sure every part is cleaned with Acyton, Wear disposable gloves for your protection and in order not to damage the composite fabric.

## 4.2 Instructions

1. Start with with closing the shaft (core tube) using the M20 lids, apply the M8 scres to do so.

2. Insert the support fix holder directly to the core tube.

3. Place the support plate and make sure to allign the holes with the M10 holes on the M20

4. Insert the M10 screws through the support plate’s holes and the threaded holes on the M20 lid.

5. Mount the Core tube on the turning system by connecting the M20 screw into the end from the previous step, use some kind of support piece for the other end.

6. Apply first insert to the system.

7. Apply insulation to the shaft and then second insert.

8. Place the support fix holder into the other end and since we dont have any space left between the support fix holder and the core tube in the secured end this time the the support fix holder will naturally have atleast 20mm of space between it and the core tube which is necessary.

9. Place the support plate and once again allign the holes with the M20 lid holes.

10. Use the M10 screws to secure this end in the same way we used for the other end.

11. Secure it by using the M20 screw.

12. Check if the system is stable and safe.

13. Clean the assembled system once again, butter the places which the resin will come into contact with using moldsealer or graphite powder.

14. Prepare the Carbon cloth should be prepared before taking out the elements of the system.

15. Prepare the pressure exerting subsystem, start by mounting the tube on the pressure system mounting device and insert the two module rings however keep in mind to leave enough space for the casing between them after that secure both ends using the M20 screws.

16. Now that your system which exerts pressure is ready do not activate it yet

17. Check if your system is stable by rotating the Shaft one more time before starting the operation.

18. start winding the fabric and applying the appropriate amount of resin.

19. After completing the first lap of the fabric on the shaft activate the system which exerts pressure on your main system.

20. Upon completing the winding process, deactivate your pressure exerting system.

21. Start putting the rowing on both sides.

22. Transfer the rest of the system to the oven system.

23. Remove the system from the oven, prepare the SR puller.

24. Place the brass ring in the SR puller with the smaller diameter facing the puller.

25. Unscrew both support plates and remove them.

26. Mount the system with the puller using the M20 screw.

27. Gently start pulling the entire system with the puller.

28. Observe as the newly produced engine starts to push the other end’s support fix holder while the core tube is moving towards the puller’s direction, make sure everything is running smoothly.

29. The fixing element connected to the puller’s screw should desconnect from the newly produced engine but still in contact with the core tube

30. Take off the core pipe from the puller.

31. Now we have only our new engine connected with the other support fix holder

32. change the side and connect the puller’s screw to the support fix holder while the brass ring remains in the previous location

33. Gently start pulling again as you observe the disconnection between the support fix holder and the new engine.

34. Extract the engine and take it back to the workshop for assessment.

35. In case any form of extra composite is on the ends, use surface finishing to remove the excess.

36. Clean everything and put everything back in the previous location before starting the operation.

37. Make sure the workshop is clean after finishing the operation.

# 5 Summary

The new technology for the production of TuCAN engines presented in this document represents the development of engine production in the SKA Rocket Section and is constantly improving, therefore we will keep expermenting with new systems to ensure advancement of future technologies. In the positive case, this technology will be developed and applied to make better, more reliable engines for high altitude applications as this is our main purpose and we are looking forward to test it and develope some details in the future.

New TuCAN Winding Technology

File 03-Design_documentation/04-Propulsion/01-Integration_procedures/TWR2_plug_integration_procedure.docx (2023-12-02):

Plug integration procedure

Twardowsky 2 propulsion

Bartosz Hyży

1. Introdution In this document, the process of integration of plug assembly will be presented and described. This procedure should be performed with caution and without usage of excessive forces on utilized components. Instructions relating to the integration of seals should be followed with particular care. As the plug system has been designed and developed according to two separate configurations differing by type of injector, the procedures for integrating the two will be presented. Here we can distinguish between two separate assemblies:

- swirl injector assembly

- the showerhead assembly

2. Swirl injector assembly procedure Basic tools needed for integration: 20 flat spanner, teflon grease, screwdriver, large seger pliers.

Before integration, the components should be cleaned with isopropyl alcohol and the integration station should be prepared by spreading stretch film on the tabletop.

Part number | Part name | Quantity
TWR.2A.4.03.02.003 | Adaptive plate | 1
TWR.2A.4.03.02.004 | Swirl element | 8
TWR.2A.4.03.02.007 | Igniter nozzle | 1
TWR.2A.4.03.02.008 | Igniter body | 1
TWR.2A.4.03.02.001/ TWR.2A.4.03.02.002 | Plug/ Test plug | 1

Table 1. List of components

Norm | Name | Size | Quantity
DIN 7991 | Countersunk screws | M3x16 | 8
Acc. to manufacturer (material AISI 316/VITON) | Met-gum stainless steel washer | M16 | 8
- | Oring NBR/VITON | 96x2,5 | 1
- | Oring NBR/VITON | 23,52x1,78 | 1
- | Flat washer NBR/VITON | Acc. to dimensions of the flange connection | 1
DIN 472 | Seger inner ring | W108 | 1

Table 2. List of standardised components

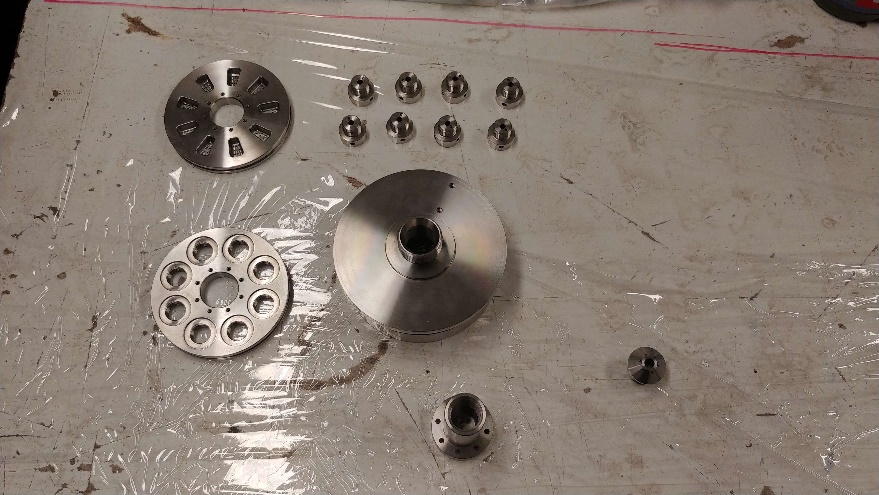
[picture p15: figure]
Obraz zawierający ziemia, brudne, w pomieszczeniu, opuszczone Opis wygenerowany automatycznie

Fig 1. Components required for integration

Prepare 8 pieces of swirl injector parts together with 8 pieces of flat rubber-metal washers for M16 threads.

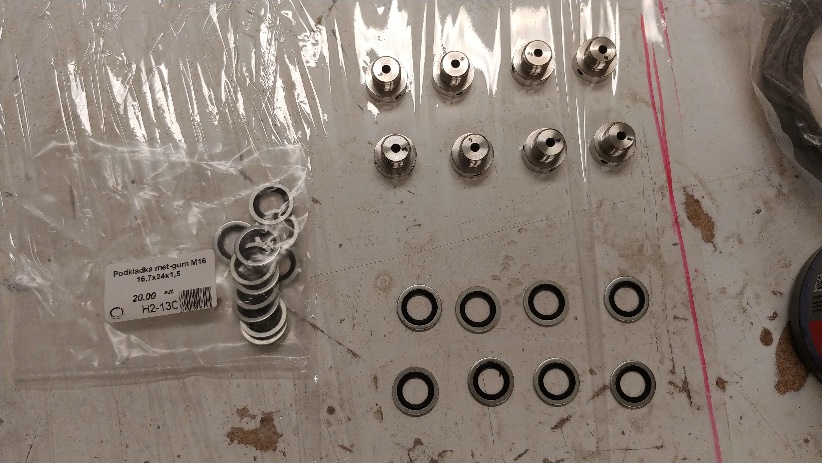
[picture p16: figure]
Obraz zawierający wyroby z metalu, w pomieszczeniu, dźwignia Opis wygenerowany automatycznie

Fig 2. Swirl injector with metal-gum washers

Teflon grease should be applied to the metal-gum washers and swirl injector threads.

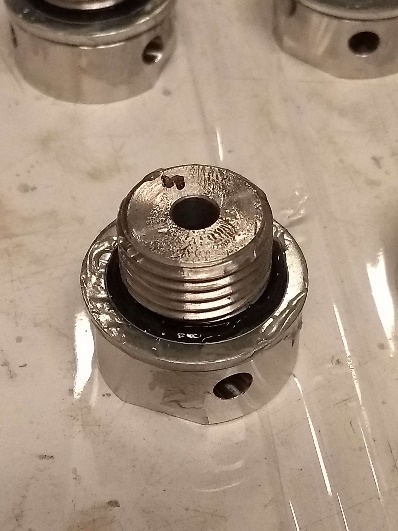
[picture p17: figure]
Obraz zawierający wyroby z metalu, Część samochodowa, Sprzęt domowy, metal Opis wygenerowany automatycznie

Fig 3. Metal-gum washers put on swirl injectors

Screw the swirl injectors thus prepared into the adaptive plate.

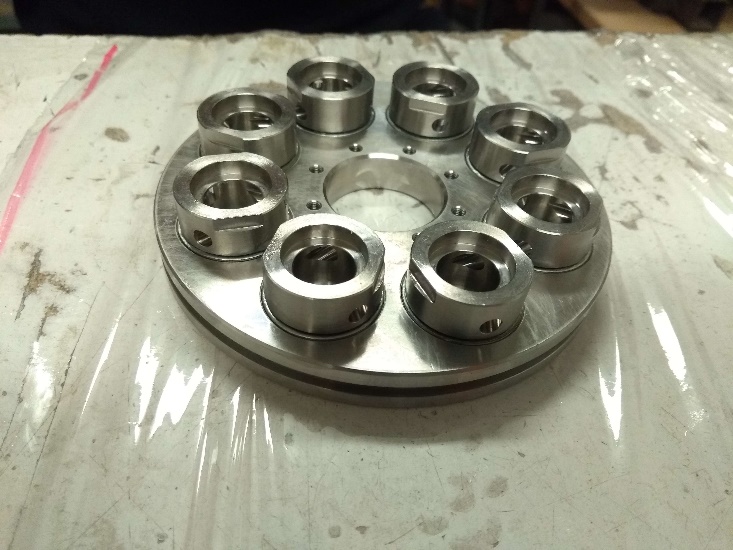
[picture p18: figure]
Obraz zawierający wyroby z metalu, Część samochodowa, orzech, metal Opis wygenerowany automatycznie

Fig 4. Swirl injectors integrated into the adaptive plate

Prepare the 96x2.5 NBR oring. Do this by coating it with a thin layer of teflon grease. Put a similar amount of grease on the groove under the oring beforehand. Then apply the oring to the outer groove of the adapter plate.

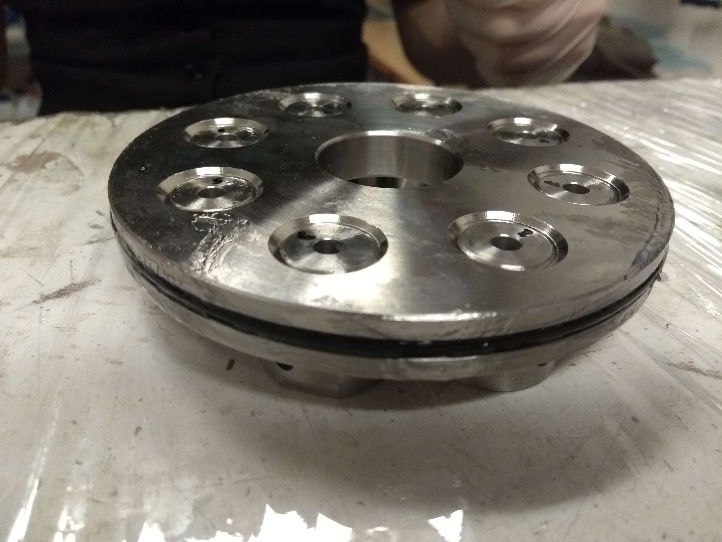
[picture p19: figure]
Obraz zawierający metal, srebro, ziemia, w pomieszczeniu Opis wygenerowany automatycznie

Fig 5. Oring applied to the adapter plate

Screw the igniter nozzle into the igniter body.

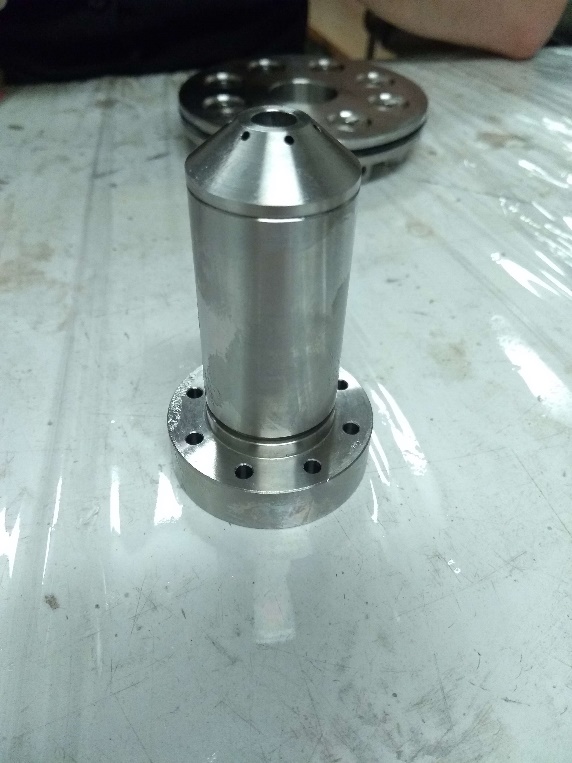
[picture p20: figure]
Obraz zawierający cylinder, srebro, Część samochodowa, stal Opis wygenerowany automatycznie

Fig 6. Igniter nozzle integrated into the igniter body

Prepare the 23.52x1.78 VITON oring. Also coat the o-ring with teflon grease, as well as the groove on its outer surface. Then apply the oring to the groove.

Then apply a flat washer to the flange connection coated with teflon grease.

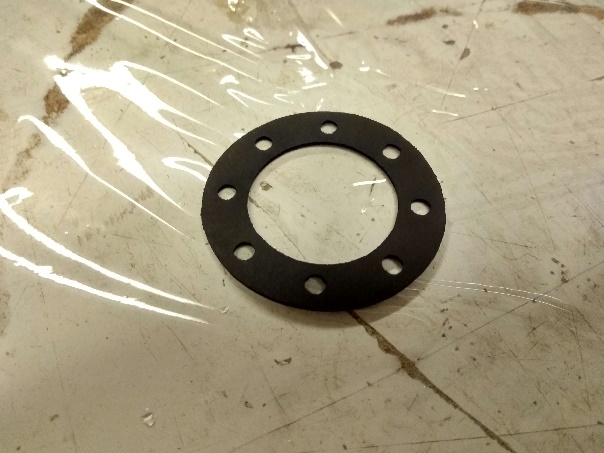
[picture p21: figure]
Obraz zawierający krąg, Część samochodowa, ziemia Opis wygenerowany automatycznie

Fig 7. Flat rubber washer for flange connection

Then insert the igniter body into the corresponding center hole in the adaptor plate.

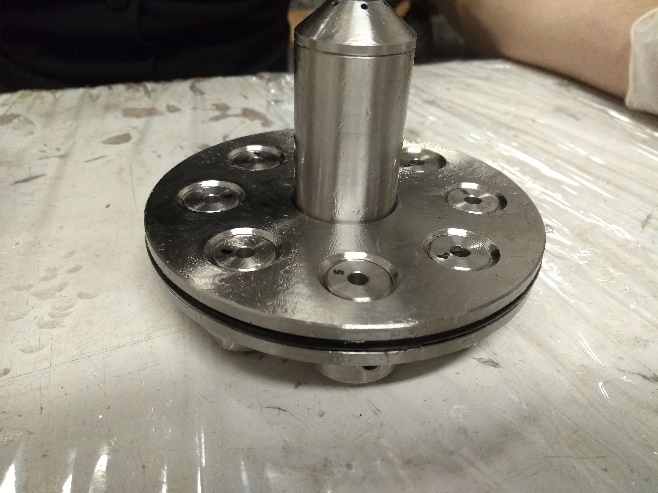
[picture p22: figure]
Obraz zawierający w pomieszczeniu, srebro, ziemia Opis wygenerowany automatycznie

Fig 8. Ignition assembly integrated into the adaptor plate

Screw in 8 M3x16 screws, fixing the igniter with the adapter plate by flange connection. The screws should be screwed in around the perimeter in a "star" order, first tentatively without bringing the cones into contact, and then screwed all the way in.

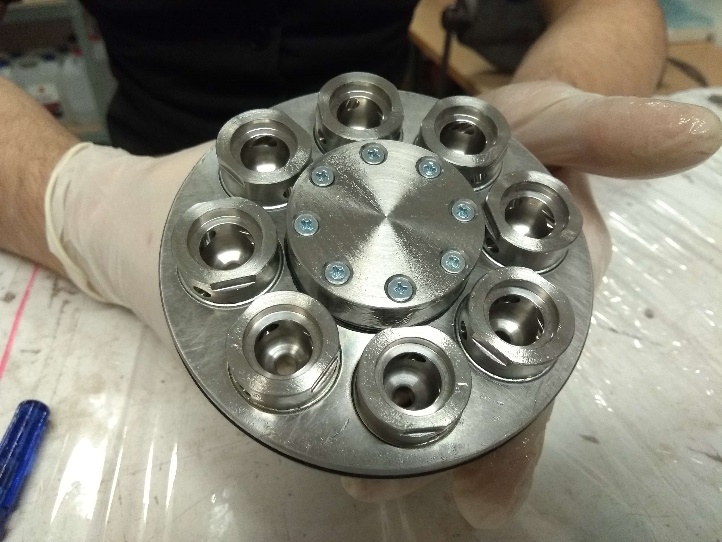
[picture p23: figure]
Obraz zawierający Część samochodowa, osoba, narzędzie, paznokieć Opis wygenerowany automatycznie

Fig 9. Integrated flange connection to the adapter plate

Then slide the thus integrated ignition-injection system into the plug body. Particular care must be taken to ensure the concentricity of the system with the plug during this step.

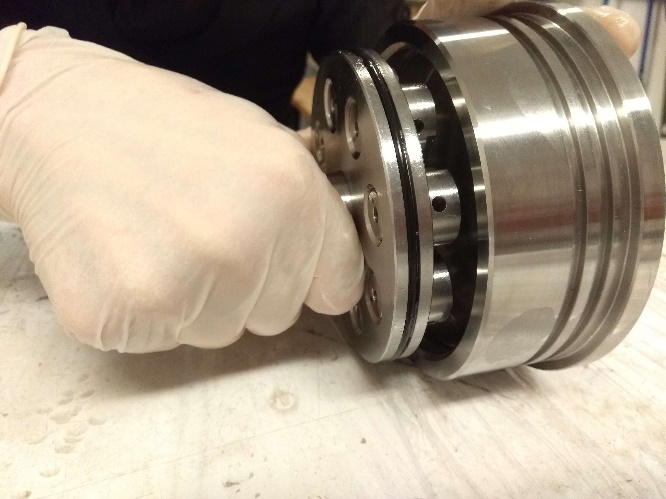
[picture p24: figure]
Obraz zawierający osoba, dłoń, podłoga, srebro Opis wygenerowany automatycznie

Fig 10. Axial insertion process of the adaptor plate assembly into the plug

In the case of resistant insertion of the component, an axisymmetric piece of metal with an orifice and a surface protection in the form of a flat rubber sheet should be provided. A piece of rubber sheet and a corresponding piece of metal higher than the protruding part of the ignitor assembly should then be placed on the surface of the adaptor plate to protect the surface of the components.

Obraz zawierający narzędzie, osoba, Obróbka metali, w pomieszczeniu Opis wygenerowany automatycznie

Fig 11. Proposed accessories for integration in case of problems in the insertion process

Obraz zawierający osoba, Obróbka metali, rzemieślnik, narzędzie Opis wygenerowany automatycznie

Fig 11. Proposed process of integration in case of problems in the insertion process

If still unsuccessful, use a screw press as desired to apply a less destructive force introduced linearly rather than percussively. Slide the plate into the plug until the entire groove for the seger ring is exposed.

The seger ring should then be inserted using seger pliers and applied in the groove locking the plate in one position.

Obraz zawierający osoba, nożyczki, w pomieszczeniu, zlew Opis wygenerowany automatycznie

Fig 12. Application process for the seger ring fastening the adaptive plate

During disintegration, use a long stick or aluminium rod when pulling out the adaptor plate. Place a rubber washer on the surface of the ignitor body on the 1" hydraulic inlet side of the plug. Then rest the stick or rod against the washer and then use a rubber mallet or line press.

Obraz zawierający osoba, ubrania, srebro, w pomieszczeniu Opis wygenerowany automatycznie

Fig 13. Disintegration process

3. Showerhead injector assembly procedure

Part number | Part name | Quantity
TWR.2A.4.03.02.006 | Showerhead injector | 1
TWR.2A.4.03.02.007 | Igniter nozzle | 1
TWR.2A.4.03.02.008 | Igniter body | 1
TWR.2A.4.03.02.001/ TWR.2A.4.03.02.002 | Plug/ Test plug | 1

Table 3. List of components

Norm | Name | Size | Quantity
DIN 7991 | Countersunk screws | M3x16 | 8
- | Oring NBR/VITON | 96x2,5 | 1
- | Oring NBR/VITON | 23,52x1,78 | 1
- | Flat washer NBR/VITON | Acc. to dimensions of the flange connection | 1
DIN 472 | Seger inner ring | W108 | 1

Table 4. List of standarised components

For the integration of the showerhead injector into the plug system, the procedure is similar to that for the integration of the swirl injector assembly. The only thing to ignore here is the step of screwing in the swirl injector components and special care must be taken during integration not to load the area around the through-holes in the showerhead plate in order to reduce the risk of damage to the component.

Obraz zawierający krąg, w pomieszczeniu, podłoga, ziemia Opis wygenerowany automatycznie

Fig 14. Oring applied to the showerhead plate

4. Revision

No. | Person responsible | Date
1 | Bartosz Hyży | 2023-12-02

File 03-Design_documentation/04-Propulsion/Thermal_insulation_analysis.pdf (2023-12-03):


# Combustion chamber thermal insulation analysis

TWR2

Szymon Życiński

STUDENTS’ SPACE ASSOCIATION Combustion chamber thermal insulation analysis

### TWR2

## Contents

1 Description of the problem | 1
2 Input data for the Analysis | 1
3 Tools used during Analysis | 4
4 Course of the analysis | 4
4.2 Getting thermal properties of the exhaust gases from NASA CEA . . . . | 7
5 Analysis output | 13
CONTENTS | Date: Page i of 13

analysis

### TWR2

## 1 Description of the problem

### 1.1 introduction to the problem

Main focus of given analysis was determining the initial thickness of combustion chamber thermal insulation. Due to hyperthermal environment, combustion processes and highly turbulent flow inside of the rocket engine’s combustion chambers the main difficulty in heat transfer related problems is approximating the heat transfer coefficient via convection between the inner wall of combustion chamber’s thermal insulation and hyperthermal environment. The values of Heat transfer coefficient is usually approximated by computational simulation or empirical equations. All of mentioned methods usually requires validation during hotfire test in order to prove that thermal insulation works fine. Additionaly to heat transfer coefficient calculations, properties of exhaust gases of given proppelant combination had to be estimated as input values.

### 1.2 description of the problem

In given case the combustion chamber is considered as a axisymmetric tube with nozzle on one end. The heat transfer in the nozzle is not considered in this analysis however due to used equations later in this analysis the nozzle geometry was needed for calculations. The thermal insulation must provide that the temperature of the combustion chamber wall is not higher than 165◦C. This temperature was choosen as maximum temperature at which carbon-epoxy composite material used for combustion chamber still posses its mechanical properties and integrity. The heat transfer problem was considered as an unsteady state.

## 2 Input data for the Analysis

### 2.1 NASA CEA input data

Choosen oxidizer and fuel for the rocket was N2O and ABS. For finding the values of thermal properties of rocket exhaust gasues, in frozen conditions, following initial data was presented in table and figure (Fig.1) below:

2 INPUT DATA FOR THE ANALYSIS | Date: Page 1 of 13

analysis

### TWR2

NASA CEA input
Name | Symbol | Value | Unit
Combustion Temperature | T0 | 3400 | K
Pressure in combustion chamber | P0 | 4.4 | MP a
Oxidizer to Fuel Ratio | O/F | 5 | -
ABS Molecular weight | M | 57.07 | kg kg·mol
ABS Enthalpy of formation | ∆H | 63.63 | kJ s
Chemical formula of ABS | C3.85H4.85N0.43


Figure 1: Specific Heat as a function of Temperature for ACRYLONITRILE BUTADIENE STYRENE

### 2.2 Insulation thermal properties

Bakelit, paper-phenol resin composite, was used as a thermal insulation of combustion chamber walls. Paper based composite was used as it doesn’t leak in comparison to cotton or fiber based composites, this fact is crucial as some of the thermal insulation faces act together with O-rings as seals for the combustion chamber.

2 INPUT DATA FOR THE ANALYSIS | Date: Page 2 of 13

analysis

### TWR2

Insulation thermal properties
Name | Symbol | Value | Unit
Density | ρi | 1300 | kg m³
Specific heat | ci | 1507 | J kgK
Thermal conductivity | λi | 0.337 | W m²K

### 2.3 Combustion chamber and Nozzle geometry

Dimensions of combustion chamber and nozzle needed for calculation are given in table and Figure (Fig. 2) below:

Nozzle geometry
Name | Symbol | Value | Unit
Nozzle throat curvature | rc | 0.02 | m
Nozzle throat diameter | D∗ | 0.045 | m
Combustion chamber diameter | D | 0.122 | m


Figure 2

2 INPUT DATA FOR THE ANALYSIS | Date: Page 3 of 13

analysis

### TWR2

## 3 Tools used during Analysis

For this analysis following programs and papaers were used:

1. Turbulent Boundary-Layer Heat Transfer from Rapidly Accelerating Flow of Rocket Combustion Gases and of Heated Air - D . R . BARTZ 1965
2. SKA, Sekcja rakietowa: Silniki CSL Opis ogólny - Tadeusz Górnicki, Warszawa kwiecień 2016
3. NASA/TP—2002-211556, NASA Glenn Coefficients for Calculating Thermodynamic Properties of Individual Species, Bonnie J. McBride, Michael J. Zehe, and Sanford Gordon Glenn Research Center, Cleveland, Ohio
4. Comparing Hydroxyl Terminated Polybutadiene and Acrylonitrile Butadiene Styrene as Hybrid Rocket Fuels, Stephen A. Whitmore,Zachary W. Peterson, and Shannon
D. Eilers† Utah State University, Logan, Utah 84322
5. Heisler graphs for transient conduction
6. NASA CEA
7. ANSYS Transient Thermal

## 4 Course of the analysis

### 4.1 Adding ABS into NASA CEA database

First step in order to start heat transfer calculation was adding ABS into NASA CEA thermodynamic database. It was necessary in order to estimate thermodynamic properties of exhaust gases inside of combustion chamber. The whole process is done according to Appendix C of [3]. The first step was finding coefficients a1, a2, a3, a4, a5, a6, a7, b1 and b2 that appear in equations 1, 2 and 3:

Cp(T)
R′

= a1T

−2 + a2T

−1 + a3 + a4T + a5T
2 + a6T

3 + a7T

4
(1)

H(T)
R′T

= −a1T

−2 + a2

ln(T)
T

+ a3 + a4

T
2

+ a5

T

2
3

+ a6

T

3
4

+ a7

T

4
5

+

b1
T

(2)

S(T)
R′

= −a1

T

−2
2

− a2T

−1 + a3ln(T) + a4T + a5

T

2
2

+ a6

T

3
3

+ a7

T

4
4

+ b2 (3)

Where:

4 COURSE OF THE ANALYSIS | Date:
Page 4 of 13

analysis

### TWR2

- T - Temperature [K]
- Cp(T) - molar heat capacity at constant pressure at temperature T for standard state [ J
mol·K

]

- H(T) - molar enthalpy at temperature T [ J
mol ]
- S(T) - entropy at temperature T for standard state [ J
mold·K

]

- R′
- universal gas constant, 8.314510 [ J
mol·K

]

The graph presented on Figure (Fig. 1) was approximated by three linear functions in three different ranges of Temperature. Enthalpy equation was calculated from H(T) = R

Cp(T)dT, fact that H(298.15) = ∆H (given in [3]) and fact that H(T) must be continuous function. The function of Entropy was omitted as changing b2 did not effect output values of needed thermodynamic properties of exhaust gases. The values final form of functions are given below:

Cp(T)
R′

= A · T + B

H(T)
R′

=

1
2

A · T

2 + B · T + C | (4)
Range of temperatures [K] | A (=a4) | B (=a3) | C (=b1)
288 - 365.809 | 0.03431971651 | -0.7893534798 | 6242.604806
365.809 - 383.747 | 0.09955056052 | -24.65137189 | 10607.07327
382.747 - 530 | 0.0212095848 | 5.411738818 | 4838.759703

The ABS molar weight was calculated from its chemical fromula C3.85H4.85N0.43 but just as ∆H its vale was taken from [4].
All of the data was added to NASA CEA files by adding it into Thermo.inp and running the program. Data was added to Thermo.inp in following format showed in Figure (Fig
3) with explanation of every line written in table below:
4 COURSE OF THE ANALYSIS | Date: Page 5 of 13

analysis

### TWR2

Record | Contents | Columns
1 | Species name of formula Coments and data sources | 1 to 16 19 to 80
2 | Number of T intervals Reference date code Chemical formula - symbols (all capitals) and numbers Zero for gas; nonzero for condensed Molecular weight Heat of formation at 298.15 K, [ J mol ] | 1 to 2 4 to 9 11 to 50 51 to 52 53 to 65 66 to 80
3 | Temperature range Number of coefficients fot Cp(T) R′ (always seven) T exponents in empirical equation for Cp(T) R′ [always -2, -1, 0, 1, 2, 3, 4] J H(298.15) − H(0) [ mol ], if aviable | 1 to 22 23 24 to 63 66 to 80
4 | First five coefficient for Cp(T) R′ | 1 to 80
5 | Last two coefficient for Cp(T) R′ Integration constants b1 and b2 | 1 to 32 49 to 80
— | Repeat 3, 4, and 5 for each interval | —


Figure 3: Example of input data for thermo.inp

The ABS thermo.inp file for given data is presented in the figure below (Fig. 4) :

4 COURSE OF THE ANALYSIS | Date: Page 6 of 13

analysis

### TWR2


Figure 4: ABS data for thermo.inp

### 4.2 Getting thermal properties of the exhaust gases from NASA

### CEA

For NASA CEA "Rocket" case was used, both frozen and equlibrum values of thermal properties were calculated but frozen values was choosen for calculations. (equilibrium values does not apply together into perfect gas equations) Input data file for NASA CEA was given as (Fig. 5):


Figure 5: Input file for NASA CEA

given input values resulted in following thermal properties of the exhaust gases:

4 COURSE OF THE ANALYSIS | Date: Page 7 of 13

analysis

### TWR2

Thermal properties of exhaust gases
Name | Symbol | Value | Units
Mollar mass | Mg | 25.787 | kg kmol
Specific heat at constant pressure | cp | 1584 | J kgK
Specific heat ratio | k | 1.2556 | -
Conductivity | λ | 0.24128 | W mK
Viscosity | µ | 0.99384·10⁻⁴ | kg ms
Prandtl number | P r | 0.6524 | -

### 4.3 Calculating heat transfer coefficient

Before calculating heat transfer coefficient following additional Properties had to be calculated:

R = cp

k − 1
k

m˙ =

πD²
∗
4

!
P0k

r
2

k+1(

k+1
k−1

)
√
kRT0

ρU =

m˙

πD²
4

(5)

Where:

- R - Specific gas constant for exhaust gases = 322.451736222 [ J
kgK ]
- m˙ - mass flow rate = 4.40508684258 [ kg
s

]

- ρU - multiplication of exhaust gases density and velocity = 376.829532785 [ kg
m²s

]

For calculating heat transfer coefficient the method showed in [1] was used. The following equation was used:

α = 0.8209850291 ·

0.026

D⁰.2

D∗
rc

0.1
µ

0.2
cp
P r⁰.6

!
(ρU)

0.8

Tw
T0

−1
Tw
2T0

+ ‘10.65
5
(6)

Where Tw is temperature of the insulation wall and " 0.8209850291" part is correction needed for SI units. Usage of Tw creats need for solving this problem iteratively. The iterative process, involving equations that will be presented later in this document, shows that Tw = 3042.6K gives us satisfying results. The calculated value of heat transfer coefficient to be
α = 1540.96613033 W
m²K

4 COURSE OF THE ANALYSIS | Date: Page 8 of 13

analysis

### TWR2

### 4.4 Calculating temperatures on insulation

Given problem is unstedy state/transient heat transfer problem. In order to calculate it we have to use Heisler graphs. Due to very limited possibilities of solving transient heat transfer problems on paper we will have to consider only small part of our combustion chamber wall and treat it as infinite plane. The Heisler graphs were taken from book titled "W. Gogół - Wymiana ciepła, tablice i wykresy" and are shown below on Figures 6 and 7. The ϑ =

T −T0
273.15−T0

where T is the temperature at given point in time. In order to estimate the temperature on the inner and outer surface of thermalinsulation Fourier and Biot numbers were calculated:

F o =

λi

ρici

·

t
δ

2

Bi =

αδ
λi

(7)

Where the total work-time of the engine is t = 9s and δ = 0.004m is the thickness of thermal insulation. With the given data values calculated properties are given in the table below:

Name | Symbol | Value | Units
Fourier number | F o | 0.086 | -
Biot Number inverse | Bi⁻¹ | 0.05467 | -
Insulation inner surface Temperature | Tw | 360.7018 | K
Insulation outer surface Temperature | Tout | 3042.6 | K

Further changes in α and Tw will give us changes of Bi that are too small to read from Heisler graphs.

4 COURSE OF THE ANALYSIS | Date: Page 9 of 13

analysis

### TWR2


Figure 6: Temperature inside the infinite plate

4 COURSE OF THE ANALYSIS | Date: Page 10 of 13

analysis

### TWR2


Figure 7: Temperature on the surface of infinite plane

4 COURSE OF THE ANALYSIS | Date: Page 11 of 13

analysis

### TWR2

### 4.5 Simulation using Ansys transient thermal

In order to validate used empirical solutions computational simulation of transient thermal case was conducted using ANSYS.
The used model is shown on the figure 8. The inner surface was treated with convection heat transfer boundary conditions with calculated α as heat transfer coefficient and T0 as ambient temperature of environment value. initial Temperature was equal to 20◦C and every other surface was treated as perfectly insulated. The solution (Fig
9) showed that results of semi-empirical equation gave similar values with around 25 K difference.


Figure 8: model used for simulation

4 COURSE OF THE ANALYSIS | Date: Page 12 of 13

analysis

### TWR2


Figure 9: solution of the simulation

## 5 Analysis output

## From conducted analysis the thickness of the combustion

chamber thermal insulation shall be be eaqual to δ = 4mm.

5 ANALYSIS OUTPUT | Date: Page 13 of 13

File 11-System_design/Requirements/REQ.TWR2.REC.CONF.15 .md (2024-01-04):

---
Title: REQ.TWR2.REC.CONF.15
Status: in-review
System: TWR2.REC
Class: Requirement
Conflicting With: 
---

## Description

Commercially designed flight computer “kits” (e.g., the Eggtimer or similar) are not
permitted as COTS. 

## Source

Spaceport: IREC Design, Test, & Evaluation Guide 2023 V1.3/ 5.7.1. -Szymon Życiński

undefined

undefined

undefined

undefined

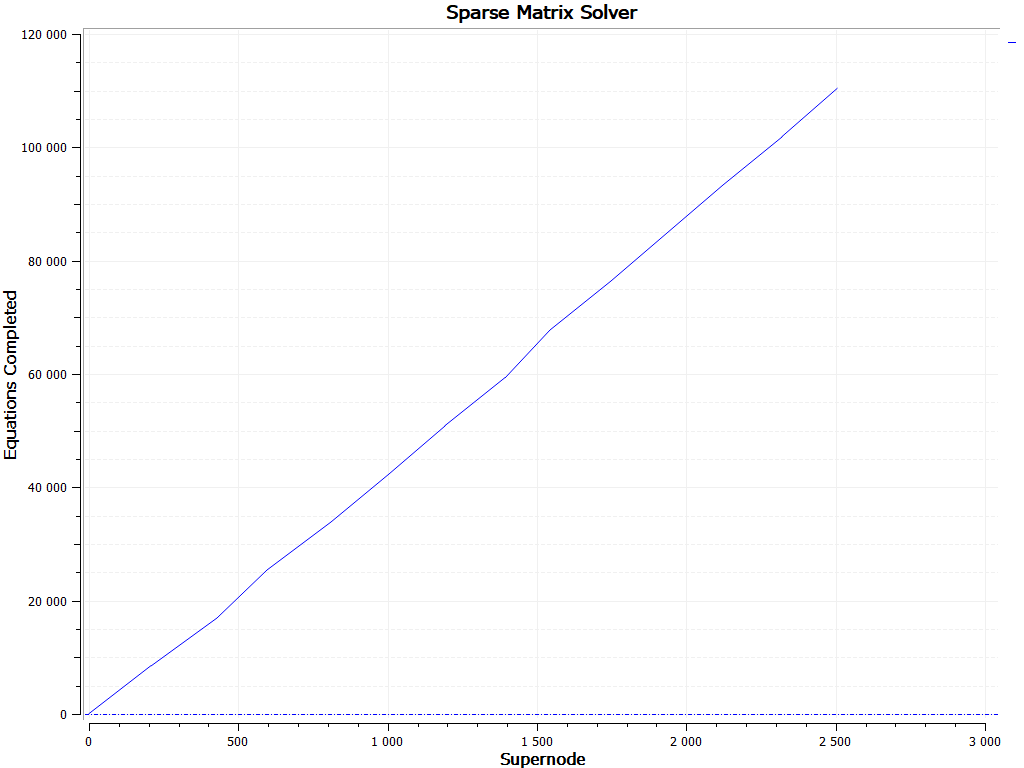
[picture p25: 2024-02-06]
01-Model/01-Rocket/COTS/Mechanical/Bearings/link_fem_input_fem3_sim1-solution_2_Sparse Matrix Solver.png

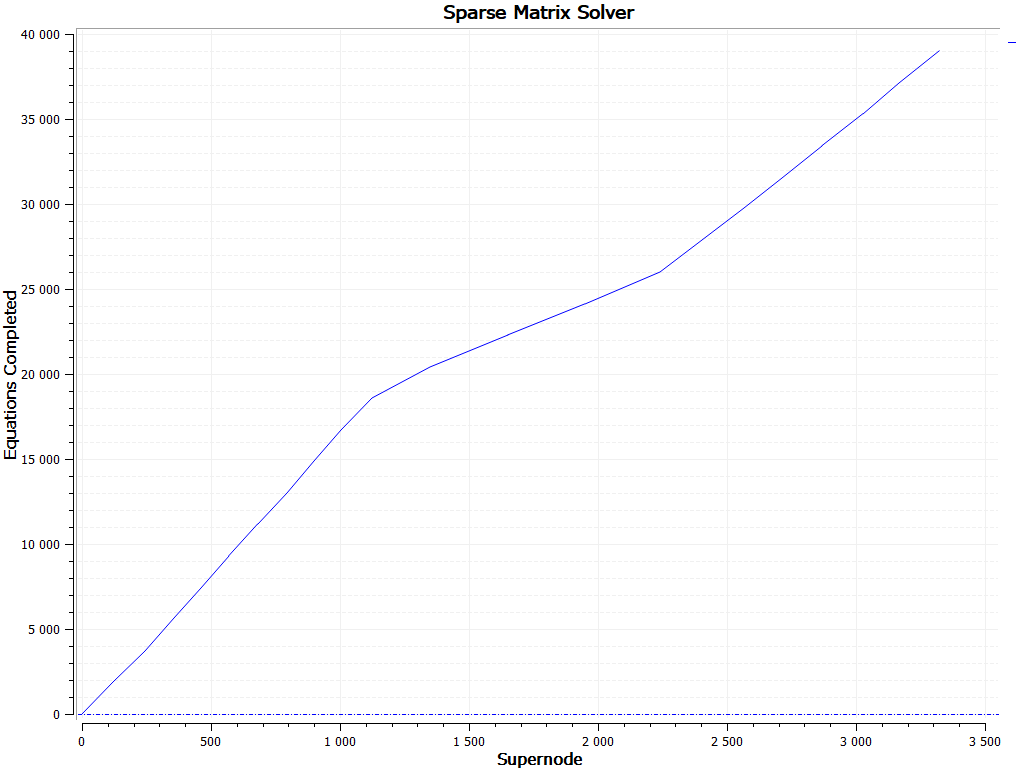
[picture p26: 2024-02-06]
01-Model/01-Rocket/COTS/Mechanical/Bearings/link_fem_input_fem3_sim1-solution_1_Sparse Matrix Solver.png

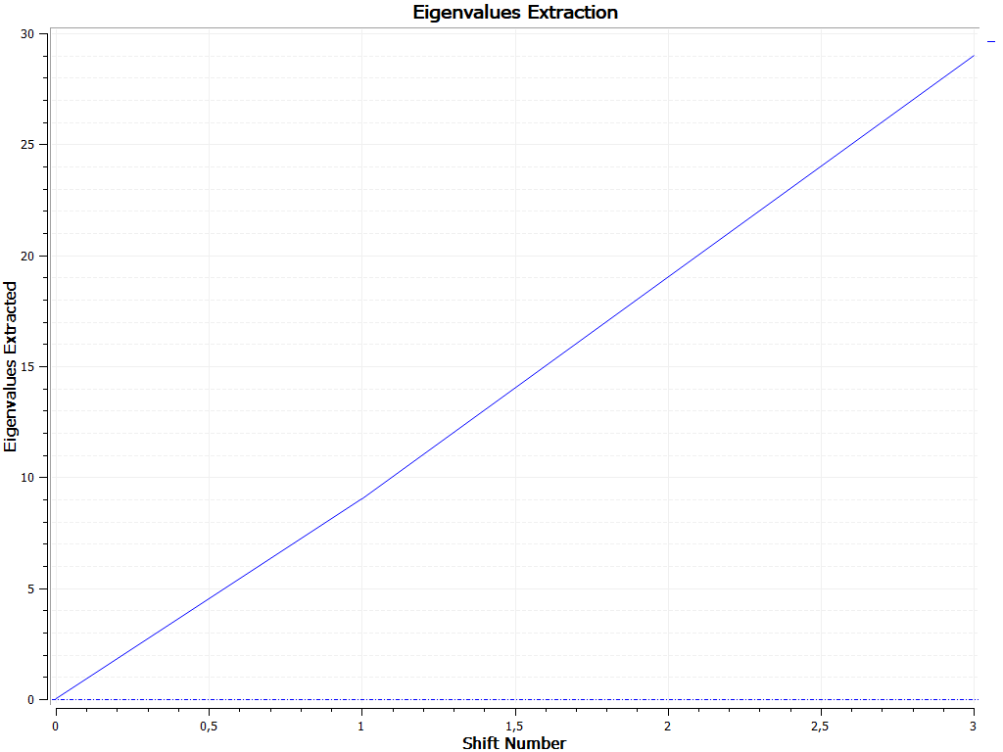
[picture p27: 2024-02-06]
01-Model/01-Rocket/COTS/Mechanical/Bearings/link_fem_input_fem3_sim1-solution_1_Eigenvalues Extraction.png

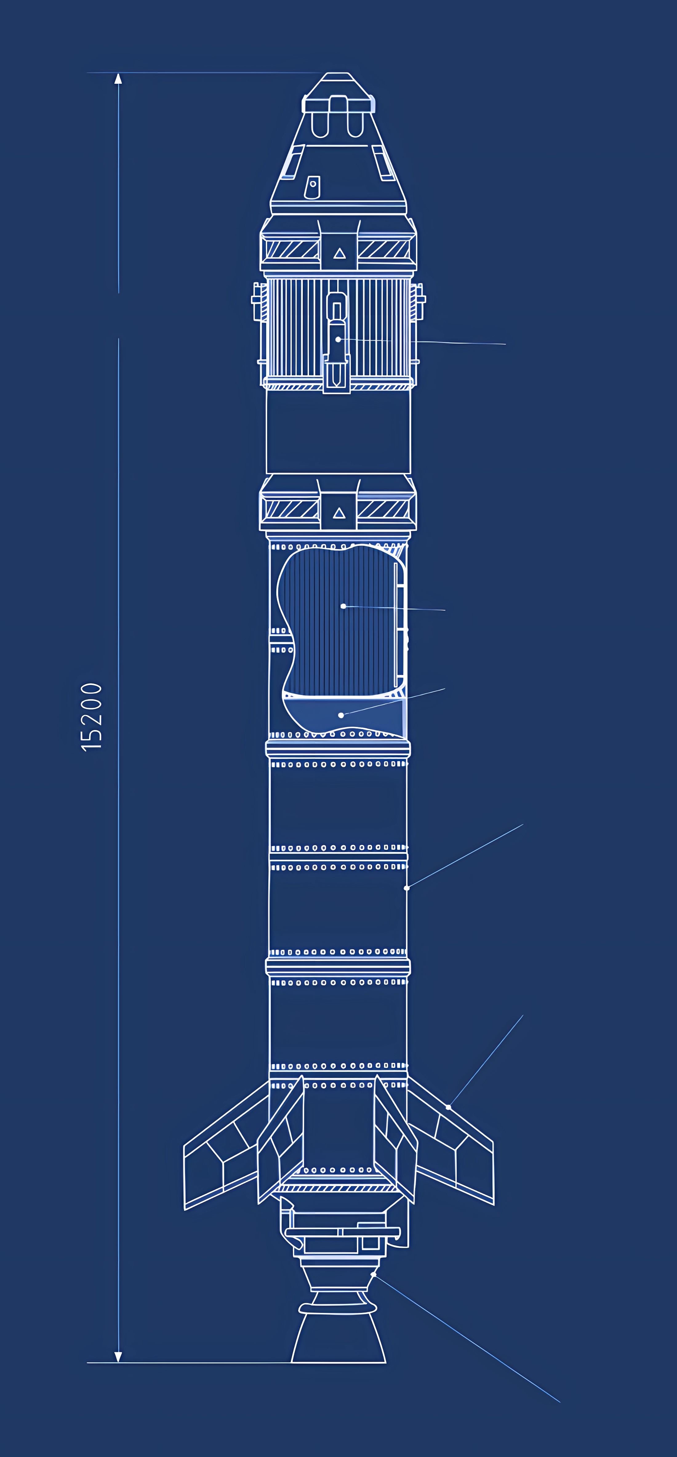
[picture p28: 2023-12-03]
69-Obsidian/assets/Rocket (1).png

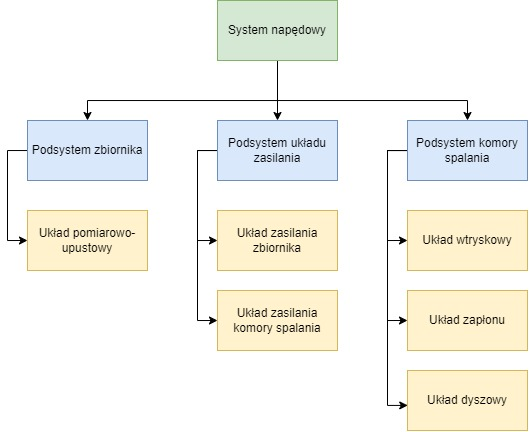
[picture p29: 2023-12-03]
69-Obsidian/assets/Pasted image 20230829113855.png

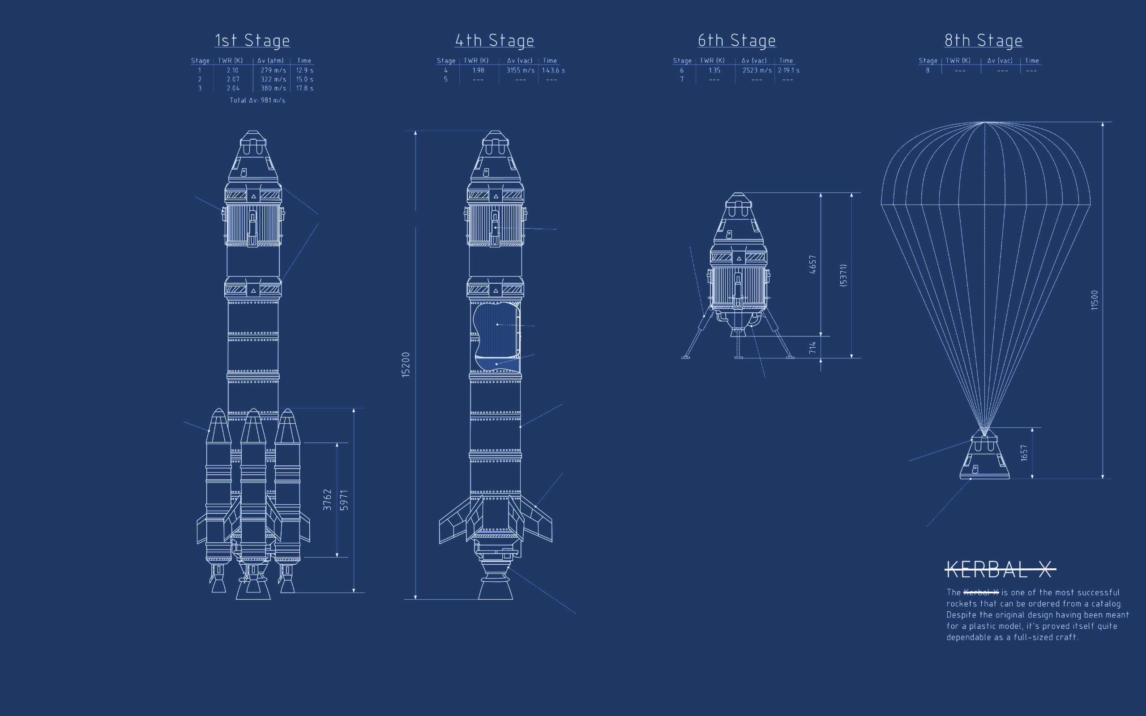
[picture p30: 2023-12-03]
69-Obsidian/assets/d829cbd0641f3bd4cf8f4fbd009d9092.png

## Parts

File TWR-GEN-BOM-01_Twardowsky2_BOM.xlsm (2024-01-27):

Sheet: BOM
Number | Name | Part per Rocket | The person responsible for the part | Location | Theoretical mass [g] | Actual Mass [g] | Status | Net Price [pln/pcs] | Gross price [pln/pcs] | The Contractor | Comment
TWR.2A.0.00.00.000 | Twardowsky 2
TWR.2A.1.00.00.000 | Nosecone | 1
TWR.2A.1.01.00.000 | Cone_body | 1 | Mirski. J
TWR.2A.1.01.00.001 | Cone_parabole | 1 | Mirski. J |  | 728.9
TWR.2A.1.01.00.002 | Cone_insert | 1 | Mirski. J |  | 189.1
TWR.2A.1.01.00.003 | Nose_insert | 1 | Mirski. J |  | 1762
TWR.2A.1.01.00.004 | Nose | 1 | Mirski. J |  | 781.2
TWR.2A.1.02.00.000 | Nosecone_electronics | 1 | Mirski. J
TWR.2A.1.02.01.000 | Electronics_stack | 1 | Mirski. J
TWR.2A.1.02.01.001 | Pyro_board | 1 | Mirski. J |  | 23.4
TWR.2A.1.02.01.002 | PLD_board | 1 | Mirski. J |  | 16.8
TWR.2A.1.02.01.003 | ESP_board | 1 | Mirski. J |  | 17.2
TWR.2A.1.02.01.004 | Ganymede_board | 1 | Mirski. J |  | 16.9
TWR.2A.1.02.01.005 | Threaded_M3_rod | 4 | Mirski. J |  | 2.3
TWR.2A.1.02.01.006 | Stack_distance_1 | 12 | Mirski. J |  | 0.8
TWR.2A.1.02.01.007 | Stack_distance_2 | 4 | Mirski. J |  | 0.6
TWR.2A.1.02.01.008 | Stack_distance_3 | 4 | Mirski. J |  | 0.4
TWR.2A.1.02.00.001 | Base | 1 | Mirski. J |  | 127
TWR.2A.1.02.00.002 | Mounting_plate_1 | 1 | Mirski. J |  | 212
TWR.2A.1.02.00.003 | Mounting_plate_2 | 1 | Mirski. J |  | 201
TWR.2A.1.02.00.004 | Distance_bolt | 4 | Mirski. J |  | 1.6
TWR.2A.1.02.00.005 | Angle | 4 | Mirski. J |  | 2.5
TWR.2A.1.02.00.006 | Turnigy_500mAh_2S_20C_7.4V_batteries_holder1 | 2 | Mirski. J |  | 0.7
TWR.2A.1.02.00.007 | Turnigy_500mAh_2S_20C_7.4V_batteries_holder_down1 | 2 | Mirski. J |  | 2
TWR.2A.1.02.00.008 | GPS_base | 1 | Mirski. J |  | 12
TWR.2A.1.02.00.009 | GPS_holder | 1 | Mirski. J |  | 2
TWR.2A.1.02.00.010 | Antenna_holder | 2 | Mirski. J |  | 0.8
TWR.2A.1.02.00.011 | Raspberry_board | 1 | Mirski. J |  | 92
TWR.2A.1.02.00.012 | Raspberry_distance_1 | 8 | Mirski. J |  | 0.2
TWR.2A.1.02.00.013 | Raspberry_distance_2 | 16 | Mirski. J |  | 0.1
TWR.2A.1.02.00.014 | EHAO_900mAh_3.7V_batteries_holder | 1 | Mirski. J |  | 0.6
TWR.2A.1.02.00.015 | TeleMega_dystance | 4 | Mirski. J |  | 0.1
TWR.2A.1.02.00.016 | D-Sub_holder | 1 | Mirski. J |  | 0.8
TWR.2A.1.02.00.017 | Threaded_M3_rod | 4 | Mirski. J |  | 4.2
TWR.2A.1.02.00.018 | EHAO_900mAh_3.7V_batteries_holder_down | 1 | Mirski. J |  | 1.6
TWR.2A.1.02.00.019 | GPX_Extreme_800maH_11V_batteries_holder_down | 2 | Mirski. J |  | 4.5
TWR.2A.1.02.00.020 | Turnigy_500mAh_2S_20C_7.4V_batteries_holder_down2 | 4 | Mirski. J |  | 1.8
TWR.2A.1.02.00.021 | Turnigy_500mAh_2S_20C_7.4V_batteries_holder2 | 4 | Mirski. J |  | 0.6
TWR.2A.1.02.00.022 | Akyga_Li-Pol_560mAh_1S_3.7V_batteries_holder | 1 | Mirski. J |  | 0.5
TWR.2A.1.02.00.023 | Akyga_Li-Pol_560mAh_1S_3.7V_batteries_holder_down | 1 | Mirski. J |  | 1.5
TWR.2A.1.02.00.024 | Gens_Ace_450mAh_11.1V_30C_SOARING_batteries_holder | 1 | Mirski. J |  | 0.7
TWR.2A.1.02.00.025 | Gens_Ace_450mAh_11.1V_30C_SOARING_batteries_holder_down | 1 | Mirski. J |  | 3.1
TWR.2A.1.02.00.026 | Gens_Ace_450mAh_7.4V_30C_SOARING_batteries_holder | 1 | Mirski. J |  | 0.7
TWR.2A.1.02.00.027 | Gens_Ace_450mAh_7.4V_30C_SOARING_batteries_holder_down | 1 | Mirski. J |  | 2.6
TWR.2A.1.02.00.028 | GPX_Extreme_800maH_11V_batteries_holder | 2 | Mirski. J |  | 1.9
COTS - ELECTRONICS | AltusMetrum_TeleMega | 1 | Mirski. J |  | 9.3
COTS - ELECTRONICS | JC_ANTENNA_GPS-MMCX-B | 1 | Mirski. J |  | 77.6
COTS - ELECTRONICS | SR_PASSIVES_433M-ANT401 | 2 | Mirski. J |  | 3.2
COTS - ELECTRONICS | Turnigy_500mAh_2S_20C_7.4V_Lipo_Pack | 6 | Mirski. J |  | 31.6
COTS - ELECTRONICS | Gens_Ace_450mAh_7.4V_30C_SOARING_JST-SYP | 1 | Mirski. J |  | 33
COTS - ELECTRONICS | Gens_Ace_450mAh_11.1V_30C_SOARING_JST-SYP | 1 | Mirski. J |  | 47
COTS - ELECTRONICS | Akyga_Li-Pol_560mAh_1S_3.7V | 1 | Mirski. J |  | 13.1
COTS - ELECTRONICS | GPX_Extreme_800mAh_11.1V_40C | 2 | Mirski. J |  | 12.9
COTS - ELECTRONICS | EHAO_900mAh_3.7V_Li_po_Rechargeable_Battery_JST | 1 | Mirski. J |  | 18
COTS - ELECTRONICS | TE_Connectivity_D-Sub_Standard_Connectors_9P_PLUG_HOUSING | 1 | Mirski. J |  | 4.5
COTS - MECHANICAL | DIN_933_M6x80 | 4 | Mirski. J |  | 20.5
COTS - MECHANICAL | DIN_7500_M3x8 | 6 | Mirski. J |  | 0.9
COTS - MECHANICAL | DIN_933_M3x28 | 4 | Mirski. J |  | 2
COTS - MECHANICAL | DIN_912_M3x10 | 4 | Mirski. J |  | 1
COTS - MECHANICAL | DIN_125_2 | 28 | Mirski. J |  | 0.01
COTS - MECHANICAL | DIN_125_3 | 38 | Mirski. J |  | 0.05
COTS - MECHANICAL | DIN_125_6 | 8 | Mirski. J |  | 0.1
COTS - MECHANICAL | UNI_5931_M2x6 | 2 | Mirski. J |  | 0.3
COTS - MECHANICAL | UNI_5931_M2x8 | 2 | Mirski. J |  | 0.4
COTS - MECHANICAL | UNI_5931_M2x10 | 8 | Mirski. J |  | 0.4
COTS - MECHANICAL | UNI_5931_M2x12 | 12 | Mirski. J |  | 0.5
COTS - MECHANICAL | UNI_6107_M2.5x14 | 16 | Mirski. J |  | 0.8
COTS - MECHANICAL | ISO_4032_M3 | 32 | Mirski. J |  | 0.4
COTS - MECHANICAL | ISO_4032_M6 | 4 | Mirski. J |  | 2.7
COTS - MECHANICAL | ISO_4032_M2 | 44 | Mirski. J |  | 0.1
COTS - MECHANICAL | ISO_10642_M3x10 | 2 | Mirski. J |  | 0.7
COTS - MECHANICAL | ISO_4036_M2.5 | 16 | Mirski. J |  | 0.3
COTS - MECHANICAL | ISO_4762_M2x10 | 20 | Mirski. J |  | 0.4
COTS - MECHANICAL | D_Sub_Jack_Screw_M3 | 2 | Mirski. J |  | 1
TWR.2A.1.00.00.001 | Nosecone_coupler | 1 | Mirski. J
COTS - MECHANICAL | ISO_4032_M3 | 8 | Mirski. J |  | 0.4
COTS - MECHANICAL | ISO_10642_M4x8 | 8 | Mirski. J |  | 1.3
COTS - MECHANICAL | DIN_125_3 | 16 | Mirski. J |  | 0.05
COTS - MECHANICAL | DIN_912_M3x10 | 8 | Mirski. J |  | 1
TWR.2A.2.00.00.000 | Payload | 1
TWR.2A.2.01.00.000 | CES | 1 | Kornel S.
TWR.2A.2.01.01.000 | CanSat_Compartment | 4 | Kornel S.
TWR.2A.2.01.01.001 | Tray | 4 | Kornel S.
TWR.2A.2.01.01.002 | Rib | 4 | Kornel S.
TWR.2A.2.01.01.01.000 | CanSat_Sabot | 8 | Kornel S.
TWR.2A.2.01.01.01.002 | Rubber_Band | 72 | Kornel S.
TWR.2A.2.01.01.01.003 | Rod_Bands | 8
TWR.2A.2.01.02.000 | Fairing | 2 | Kornel S.
TWR.2A.2.01.02.001 | Flap | 2 | Kornel S.
TWR.2A.2.01.02.002 | Hook | 4 | Kornel S.
TWR.2A.2.01.02.003 | Tensioner_block | 8
COTS_MECHANICAL | ISO_7047_M2x5 | 8
COTS_MECHANICAL | DIN_934_M2 | 8
TWR.2A.2.01.03.000 | Cam-HD_Set | 1 | Kornel S.
 | Camera_Waveshare_HD_G_OV5647 | 2 | Kornel S.
TWR.2A.2.01.03.001 | Cam-HD_Mount | 1 | Kornel S.
TWR.2A.2.01.03.002 | Cam_HD_Mount_outer | 1
COTS_MECHANICAL | DIN_934_M2 | 4
COTS_MECHANICAL | DIN_7985_M2x5 | 4
TWR.2A.2.01.04.000 | electronics stack | 1 | Kornel S.
TWR.2A.2.01.04.001 | Board_holder | 1 | Kornel S.
TWR.2A.2.01.04.002 | second_board_holder | 1
COTS_ELECTRONICS | Camera_connection_board | 1
COTS_ELECTRONICS | SWC_Switch_Board | 1
COTS_MECHANICAL | DIN_7985_M2_10 | 4 | Kornel S.
COTS_MECHANICAL | threaded_rod_M2x24 | 3
COTS_MECHANICAL | DIN_934_M2 | 16
TWR.2A.2.01.00.001 | Casing | 1 | Kornel S.
TWR.2A.2.01.00.002 | Frame_Plate_Bottom | 1 | Kornel S.
 |  |  | Kornel S.
TWR.2A.2.01.00.003 | Frame_Plate_Upper | 1 | Kornel S.
 |  |  | Kornel S.
TWR.2A.2.01.00.004 | Cotter | 8 | Kornel S.
TWR.2A.2.01.00.005 | Tensioner_block_stat | 6 | Kornel S.
TWR.2A.2.01.00.007 | Distance_M4 | 8 | Kornel S.
TWR.2A.2.01.00.008 | Pad | 2 | Kornel S.
TWR.2A.2.01.00.009 | Distance_M2 | 4
COTS_ELECTRONICS | thermoknife_RTS-01-5A | 2
COTS_ELECTRONICS | Camera_extension_board | 1
COTS_MECHANICAL | ISO_10642_M3x10 | 56
COTS_MECHANICAL | DIN_912_M3_10 | 44
COTS_MECHANICAL | ISO_4762_M4x25 | 2
COTS_MECHANICAL | ISO_4032_M4 | 2
COTS_MECHANICAL | ISO_4032_M3 | 131
COTS_MECHANICAL | ISO_4032_M2 | 4
COTS_MECHANICAL | DIN_580_M6 | 1
COTS_MECHANICAL | DIN_7985_M2x12 | 4
COTS_MECHANICAL | ISO_4032_M6 | 1
COTS_OTHER | Spring
TWR.2A.2.02.00.000 | CanSat 1 | 2
TWR.2A.2.02.00.001 | Upper_shell | 2 | Szalkowski K. |  | 30
TWR.2A.2.02.00.002 | Lower_shell | 2 | Szalkowski K. |  | 42.6
TWR.2A.2.02.00.003 | Main_plate_v2 | 2 | Szalkowski K. |  | 35
TWR.2A.2.02.00.004 | Spool | 4 | Szalkowski K. |  | 1
TWR.2A.2.02.00.005 | Bracket_motor | 4 | Szalkowski K. |  | 2
TWR.2A.2.02.00.006 | Shield_PCB | 2 | Legutko D. |  | 31
TWR.2A.2.02.00.007 | Spacer_sleeve | 8 | Szalkowski K. |  | 0.3
TWR.2A.2.02.00.008 | Plate_side_element | 4 | Szalkowski K.
COTS_ELECTRICAL | Raspberry_Cam_v2 | 2
COTS_ELECTICAL | Rasberry_pi_zero | 2
COTS_ELECTRICAL | Keystone_18650_battery_holder | 2
COTS_ELECTRICAL | Battery_Li_Ion_18650 | 4
COTS_ELECTRICAL | N20_DC_motor | 4
COTS_ELECTRICAL | Potentiometer_T910X | 4
COTS_ELECTRICAL | APRS_transmitter | 2 |  |  | 57
COTS - MECHANICAL | ISO_7045_M2x8 | 12
COTS - MECHANICAL | ISO_7045_M2x10 | 14
COTS - MECHANICAL | ISO_7046_M4x6 | 8
COTS - MECHANICAL | ISO_4032_M4 | 8
COTS - MECHANICAL | DIN_965_M2X16 | 8
COTS - MECHANICAL | ISO_4032_M2 | 34
TWR.2A.2.03.00.000 | CanSat 2 | 2
TWR.2A.2.03.00.001 | Shell | 2 | Szalkowski K. |  | 119
TWR.2A.2.03.00.002 | shell_cover | 2 | Szalkowski K. |  | 20
TWR.2A.2.03.00.003 | Tube | 2 | Szalkowski K.
TWR.2A.2.03.00.004 | Air_sensor_holder | 2 | Szalkowski K.
TWR.2A.2.03.00.005 | APRS_cam_mount | 2 | Szalkowski K.
TWR.2A.2.03.00.006 | holder_PCB | 2 | Szalkowski K.
TWR.2A.2.03.00.007 | LiPol_holder | 2
TWR.2A.2.03.00.008 | CanSat2_PCB | 2 | Maciej Mikulski
COTS_ELECTRICAL | GP2Y1014AU0F | 2
COTS_ELECTRICAL | camera(of which i dont know anything about) | 2
COTS_ELECTRICAL | LiPol_1S_500mAh | 2
COTS_ELECTRICAL | APRS_transmitter | 2
COTS - MECHANICAL | DIN_914_M3x12 | 12
COTS - MECHANICAL | ISO_4032_M3 | 18
COTS - MECHANICAL | DIN_934_M2 | 6
COTS - MECHANICAL | DIN_7985_M2_8 | 6
COTS - MECHANICAL | ISO_10642_M3x8 | 2
COTS - MECHANICAL | ISO_10642_M3x16 | 4
TWR.2A.2.03.00.002 | CanSat_Parachute | 4
COTS_ELECTRONICS | Li-Pol_Redox_1300mAh_30C_3S_11.1V | 1
TWR.2A.3.00.00.000 | Recovery_system | 1
TWR.2A.3.01.00.000 | Body_tube | 1 | Pytlak D.
TWR.2A.3.01.00.001 | Tube | 1 | Pytlak D.
TWR.2A.3.01.00.002 | Upper_insert | 1 | Pytlak D.
TWR.2A.3.01.00.003 | Lower_insert | 1 | Pytlak D.
COTS - MECHANICAL | ISO 10642 M4x12 | 16
TWR.2A.3.02.00.000 | Main_parachute | 1 | Pytlak D.
TWR.2A.3.02.00.001 | Main_parachute_material | 1 | Pytlak D.
TWR.2A.3.02.00.002 | Main_parachute_tape | 1 | Pytlak D.
TWR.2A.3.02.00.003 | Main_parachute_bag | 1 | Pytlak D.
TWR.2A.3.03.00.000 | Drogue_parachute | 1 | Pytlak D.
TWR.2A.3.03.00.001 | Drogue_parachute_material | 1 | Pytlak D.
TWR.2A.3.03.00.002 | Drogue_parachute_tape | 1 | Pytlak D.
TWR.2A.3.03.00.003 | Drogue_parachute_bag | 1 | Pytlak D.
TWR.2A.3.04.00.000 | Upper_connector | 1 | Pytlak D.
TWR.2A.3.04.01.000 | Connector | 1 | Pytlak D.
TWR.2A.3.04.01.001 | Connector | 1 | Pytlak D.
TWR.2A.3.04.01.002 | Main_fastening_base | 1 | Pytlak D.
TWR.2A.3.04.01.003 | Mortar | 2 | Pytlak D.
TWR.2A.3.04.01.004 | Stabilizer | 2 | Pytlak D.
TWR.2A.3.04.01.005 | Drogue_fastening_base | 2 | Pytlak D.
COTS - MECHANICAL | ISO_10642_M4x12 | 12 | Pytlak D.
COTS - MECHANICAL | ISO_4014_M8x40_Polymide | 2 | Pytlak D.
COTS - MECHANICAL | ISO_7089_8 | 2 | Pytlak D.
COTS - MECHANICAL | ISO_4014_M8x40 | 1 | Pytlak D.
COTS - MECHANICAL | ISO_4032_M8 | 1 | Pytlak D.
COTS - MECHANICAL | ISO_4032_M4 | 12 | Pytlak D.
COTS - MECHANICAL | ISO_7089_4 | 16 | Pytlak D.
COTS - MECHANICAL | ISO_4032_M2 | 4 | Pytlak D.
COTS - MECHANICAL | ISO_4762_M2x20 | 4 | Pytlak D.
COTS - MECHANICAL | DIN_7984_M4x10 | 4 | Pytlak D.
COTS - MECHANICAL | DIN_934_M4 | 4 | Pytlak D.
COTS - MECHANICAL | ISO_4762_M1,6x10 | 4 | Pytlak D.
COTS - MECHANICAL | ISO_4032_M1,6 | 2 | Pytlak D.
TWR.2A.3.05.00.000 | Lower_connector | 1 | Pytlak D.
TWR.2A.3.05.00.001 | Lower_connector | 1 | Pytlak D.
 |  |  | Pytlak D.
COTS - MECHANICAL | ISO_1207_M3x8_Polymide | 4 | Pytlak D.
COTS - MECHANICAL | ISO_4027_M2x2_5 | 2 | Pytlak D.
TWR.2A.3.06.00.000 | Plate | 1 | Pytlak D.
TWR.2A.3.06.00.001 | Aluminium_plate | 1 | Pytlak D.
 |  |  | Pytlak D.
TWR.2A.3.06.01.000 | Charge | 2 | Pytlak D.
TWR.2A.3.06.01.001 | Charge_Top | 2 | Pytlak D.
 |  |  | Pytlak D.
TWR.2A.3.06.01.002 | Charge_Bottom | 2 | Pytlak D.
 |  |  | Pytlak D.
TWR.2A.3.06.01.003 | Primer | 4 | Pytlak D.
 |  |  | Pytlak D.
 |  |  | Pytlak D.
TWR.2A.3.06.01.004 | Powder | 4 | Pytlak D.
 |  |  | Pytlak D.
 |  |  | Pytlak D.
COTS - MECHANICAL | ISO_7089_M5 | 2 | Pytlak D.
COTS - MECHANICAL | ISO_4032_M5 | 2 | Pytlak D.
COTS - MECHANICAL | DIN_444_M5_small | 2 | Pytlak D.
TWR.2A.3.07.00.000 | Slider | 1 | Pytlak D.
TWR.2A.3.07.00.001 | Slider | 1 | Pytlak D.
 |  |  | Pytlak D.
TWR.2A.3.07.00.002 | Slider_nut | 1 | Pytlak D.
 |  |  | Pytlak D.
TWR.2A.3.08.00.000 | Weipu | 1 | Pytlak D.
TWR.2A.3.08.00.001 | Weipu_mount | 1 | Pytlak D.
 |  | 1
COTS_ELECTRONICS | Weipu_female | 1
COTS_ELECTRONICS | Weipu_male | 1
TWR.2A.3.09.00.000 | Internal_Cam_Board | 1
TWR.2A.3.09.01.000 | Camera_Conn_Board | 1
TWR.2A.3.09.01.001 | Cam_board_top | 1
TWR.2A.3.09.01.002 | Cam_board_bottom | 1
COTS_ELECTRONICS | IDC_Port | 2
COTS_ELECTRONICS | FFC_Port | 2
TWR.2A.3.10.00.000 | External_Cam | 1
TWR.2A.3.10.00.001 | External_Cam_Mount | 1
TWR.2A.3.10.00.002 | External_Cam_Base | 1
COTS_ELECTRONICS | Camera_Fish_Eye_ZeroCam_OVE5647_5MPx | 1
COTS_MECHANICAL | ISO_4762_M2x8 | 4
COTS_MECHANICAL | ISO_4032_M2 | 4
TWR.2A.3.11.00.000 | Connector_D-26 | 1
TWR.2A.3.11.00.001 | D-26_Mount | 1
COTS_ELECTRONICS | Signalorigin_D-sub26 | 1
COTS_MECHANICAL | ISO_4762_M2x6 | 2
COTS_MECHANICAL | ISO_4032_M2 | 2
TWR.2A.3.12.00.000 | Bridge | 1
TWR.2A.3.12.00.001 | Printed_Plate | 1 | Pytlak D.
TWR.2A.3.12.00.002 | Pyro_PCB_GNMD_V2 | 1
TWR.2A.3.12.00.003 | Pyro_PCB_TLM_V2 | 1
TWR.2A.3.12.00.004 | Plate_Leg | 4 | Pytlak D.
COTS_ELECTRONICS | XT-20G_F | 1
COTS_MECHANICAL | ISO_4762_M3x8 | 8 | Pytlak D.
COTS_MECHANICAL | ISO_4032_M2 | 8 | Pytlak D.
COTS_MECHANICAL | ISO_4762_M1,6x8 | 2 | Pytlak D.
TWR.2A.3.13.00.000 | Internal_IMX135 | 1
TWR.2A.3.13.00.001 | Camera_Cover_Top | 1
TWR.2A.3.13.00.002 | Camera_Cover_Walls | 1
COTS_ELECTRONICS | IMX135 | 1
COTS_ELECTRONICS | RJ45 | 1
TWR.2A.3.14.00.000 | Container | 1 | Pytlak D.
 |  |  | Pytlak D.
TWR.2A.3.15.00.000 | Connecting_elements | 1 | Pytlak D.
TWR.2A.3.15.01.000 | Pasamon_tapes | 1 | Pytlak D.
TWR.2A.3.15.01.001 | Eyebolt - Swivel_drogue_parachute | 1 | Pytlak D. |  |  |  |  |  |  |  | 9,6 m
TWR.2A.3.15.01.002 | Drogue_parachute - Swivel_drogue_parachute | 1 | Pytlak D. |  |  |  |  |  |  |  | 2,3 m
TWR.2A.3.15.01.003 | Swivel_drogue_parachute - shackle | 1 | Pytlak D. |  |  |  |  |  |  |  | 0,55 m
TWR.2A.3.15.01.004 | Nosecone - swivel_drogue_parachute | 1 | Pytlak D. |  |  |  |  |  |  |  | 8 m
TWR.2A.3.15.01.005 | Nosecone - swivel_main_parachute | 1 | Pytlak D. |  |  |  |  |  |  |  | 2,1 m
TWR.2A.3.15.01.006 | Main_parachute_tape | 1 | Pytlak D. |  |  |  |  |  |  |  | 0,8 m
TWR.2A.3.15.02.000 | Lines | 1 | Pytlak D.
TWR.2A.3.15.02.001 | Main_Parachute_bag | 1 | Pytlak D. |  |  |  |  |  |  |  | 0,15 m
TWR.2A.3.15.02.002 | Drogue_Parachute_bag | 1 | Pytlak D. |  |  |  |  |  |  |  | 0,1 m
TWR.2A.3.15.03.000 | Others | 1 | Pytlak D.
TWR.2A.3.15.03.001 | Steel_cable | 1 | Pytlak D. |  |  |  |  |  |  |  | 0,15 m
TWR.2A.3.15.03.002 | Kevlar reinforcement | 1 | Pytlak D.
TWR.2A.3.15.03.003 | Rubber_tape | 2 | Pytlak D. |  |  |  |  |  |  |  | 0,5 m
COTS_MECHANICAL | Shackle | ? | Pytlak D.
COTS_MECHANICAL | Swivel | 2 | Pytlak D.
TWR.2A.4.00.00.000 | Propulsion_system |  | Hyży B.
TWR.2A.4.01.00.000 | Tank | 1 | Chernenko P.
TWR.2A.4.01.00.001 | Tank_body | 1 | Chernenko P.
TWR.2A.4.01.00.002 | Tank_end_bottom | 1 | Chernenko P.
TWR.2A.4.01.00.003 | Tank_end_top | 1 | Chernenko P.
TWR.2A.4.01.00.004 | Separation | 1 | Chernenko P.
TWR.2A.4.01.01.000 | MVS |  | Chernenko P.
TWR.2A.4.01.01.001 | coupling | 1 | Chernenko P.
TWR.2A.4.01.01.002 | tee | 1 | Chernenko P.
TWR.2A.4.01.01.003 | PBM4 | 1 | Chernenko P.
TWR.2A.4.01.01.004 | electrovalve | 1 | Chernenko P.
TWR.2A.4.01.02.000 | Gas_exhaust |  | Dzik M.
TWR.2A.4.01.02.001 | Gas_exhaust_hold | 1 | Dzik M.
TWR.2A.4.01.02.002 | Gas_exhaust_port | 1 | Dzik M.
TWR.2A.4.01.03.000 | Sensor_adaptor |  | Dzik M.
TWR.2A.4.01.03.001 | Weld_connect | 2 | Dzik M.
TWR.2A.4.01.03.002 | Adaptor | 1 | Dzik M.
TWR.2A.4.01.03.003 | Pressure_connect | 1 | Dzik M.
TWR.2A.4.01.03.004 | Pressure_tube | 1 | Dzik M.
TWR.2A.4.01.03.005 | Pyro_tube | 1 | Dzik M.
TWR.2A.4.01.04.000 | Slizgacz |  | Dzik M.
TWR.2A.4.01.04.001 | Slizgacz_podstawa | 1 | Dzik M.
TWR.2A.4.01.04.002 | Teflon | 1 | Dzik M.
TWR.2A.4.01.04.003 | Teflon | 1 | Dzik M.
TWR.2A.4.01.04.004 | Gumowa_podkladka | 1 | Dzik M.
TWR.2A.4.01.04.005 | Podkladka_plaska | 1 | Dzik M.
TWR.2A.4.02.00.000 | Feeding_system | 1 | Lechowicz I.
TWR.2A.4.02.01.000_Pyro_valve | Pyro valve | 1 | Lechowicz I.
TWR.2A.4.02.01.001_case | Case | 1 | Lechowicz I.
TWR.2A.4.02.01.002_rod | Rod | 1 | Lechowicz I.
TWR.2A.4.02.01.003_pyro_plug | Pyro plug | 1 | Lechowicz I.
TWR.2A.4.02.01.004_back_plug | Back plug | 1 | Lechowicz I.
TWR.2A.4.02.01.005_print | Print | 1 | Lechowicz I.
TWR.2A.4.02.01.006_plug_tool | Plug tool | 1 | Lechowicz I.
TWR.2A.4.02.01.007_plug_tool_pin | Plug tool pin | 1 | Lechowicz I.
TWR.2A.4.02.01.008_plug_hold | Plug hold | 1 | Lechowicz I.
TWR.2A.4.02.01.009_sealant | Sealant | 1
TWR.2A.4.02.01.010_ignitor | Ignitor | 2
TWR.2A.4.02.01.011_smokeless_gunpowder | Smokeless gunpowder | 1
COTS - MECHANICAL | o-ring_1x18_nbr | 2
COTS - MECHANICAL | O-ring_fi18xfi1_viton | 2
COTS - MECHANICAL | DIN_912_M2x3 | 1
COTS - MECHANICAL | DN 1214 HD | 1
COTS - MECHANICAL | DN 1212 HD ES | 1
COTS - MECHANICAL | 1-SG-006-2-WR513_quick_connect_male | 1
TWR.2A..4.02.03.000_tee_1_2_1_4 | tee 1 2 1 4 | 1
TWR.2A.4.02.02.000_adapter | Adapter | 1 | Lechowicz I.
COTS - MECHANICAL | o-ring_1x18_nbr_v2 x 2 | 2 | Lechowicz I.
TWR.2A.4.02.02.002_tube | Tube | 1
TWR.2A.4.02.02.003_cone_conector | Cone conector | 1 | Lechowicz I.
TWR.2A.4.02.02.001_adapt | Adapt | 1
TWR.2A.4.03.00.000 | Combustion_chamber | 1 | Matczak M.
TWR.2A.4.03.00.001 | Grain | 1 | Matczak M.
TWR.2A.4.03.00.002 | Barrel | 2 | Matczak M.
TWR.2A.4.03.00.003 | Body | 1 | Matczak M.
TWR.2A.4.03.00.004 | Insulation | 1 | Matczak M.
TWR.2A.4.03.00.005 | Izo_Plug | 1 | Matczak M.
TWR.2A.4.03.01.000 | Nozzle | 1 | Matczak M.
TWR.2A.4.03.01.001 | Nozzle_Body | 1 | Matczak M.
TWR.2A.4.03.01.002 | Insert | 1 | Matczak M.
TWR.2A.4.03.01.003 | Flange | 1 | Matczak M.
TWR.2A.4.03.01.004 | Plug | 1 | Matczak M.
TWR.2A.4.03.02.000 | Injector | 1 | Matczak M.
TWR.2A.4.03.02.001 | Plug | 1 | Matczak M.
TWR.2A.4.03.02.002 | Showerhead | 1 | Matczak M.
TWR.2A.4.03.03.000 | Initial_Mass | 1 | Matczak M.
TWR.2A.4.03.03.001 | Print_Cup | 1 | Matczak M.
TWR.2A.4.03.03.002 | Initial_Mass_Material | 1 | Matczak M.
TWR.2A.4.03.03.003 | Cover | 1 | Matczak M.
TWR.2A.4.03.04.004 | Black_Powder | 1 | Matczak M.
TWR.2A.4.03.04.005 | Primer | 2 | Matczak M.
TWR.2A.4.04.00.000 | Intersection | 1 | Matczak M.
TWR.2A.4.04.00.001 | Chamber_Fairing | 1 | Matczak M.
TWR.2A.4.04.00.002 | Reductive_Fairing | 1 | Matczak M.
TWR.2A.4.04.00.003 | Insert_Top | 1 | Matczak M.
TWR.2A.4.04.00.004 | Insert_Bottom | 1 | Matczak M.
TWR.2A.4.04.00.005 | Connector_Holder | 2 | Matczak M.
COTS - MECHANICAL | ISO_10642_M3x6 | 40
COTS - MECHANICAL | ISO_10642_M3x10 | 8
TWR.2A.4.04.01.000 | Fins | 1 | Matczak M.
TWR.2A.4.04.01.001 | Bottom_clamp | 1 | Matczak M.
TWR.2A.4.04.01.002 | Fin | 4 | Matczak M.
TWR.2A.4.04.01.003 | Clamp | 1 | Matczak M.
COTS - MECHANICAL | ISO_4032_M4 | 12
COTS - MECHANICAL | ISO_7089_Washer_5x10 | 24
COTS - MECHANICAL | ISO_7379_M4x8 Screw | 12
TWR.2A.5.00.00.000 | GSE
TWR.2A.5.01.00.000 | Launchpad |  | VACAT
 | Part 1
 | Part 2
 | Part 3
TWR.2A.5.02.00.000 | Bootles_mounting |  | Makała O.
 | Part 1
 | Part 2
 | Part 3
TWR.2A.5.03.00.000 | Tank_filling_system |  | Śliwiński M.
 | Part 1
 | Part 2
 | Part 3
TWR.2A.6.00.00.000 | Test_equipment
TWR.2A.6.01.00.000 | Recovery_Test | 1 | Pytlak D.
TWR.2A.6.01.01.000 | Weights | 1
TWR.2A.6.01.01.001 | Weight_alu_small | 1
TWR.2A.6.01.01.002 | Weight_alu_big | 1
TWR.2A.6.01.01.003 | Weight_brass_small | 1
TWR.2A.6.01.01.004 | Weight_alu_engine | 1
TWR.2A.6.01.01.005 | Weight_brass_engine | 1
TWR.2A.6.01.02.000 | Electronics | 1
TWR.2A.6.01.02.001 | Electro_stand | 1
TWR.2A.6.01.02.002 | Electro_cover | 1
TWR.2A.6.01.02.003 | Electronics | 1
COTS - MECHANICAL | M16_rod_small | 1
COTS - MECHANICAL | M16_rod_long | 1
COTS - MECHANICAL | ISO_4032_M16 | 2
COTS - MECHANICAL | DIN_439_M16 | 1
COTS - MECHANICAL | ISO_7089_16 | 3
COTS - MECHANICAL | Screw_Uni_9817_M3x16 | 6
COTS - MECHANICAL | ISO_7089_3 | 2
COTS - MECHANICAL | DIN_582_M16 | 1
COTS - MECHANICAL | DIN_444_M5x50 | 3
COTS - MECHANICAL | BN_1054_press_in_threaded_inserts_M3_Brass | 6
TWR.2A.6.02.00.000 | Combustion_Chamber_Tests
TWR.2A.6.02.01.000 | Chamber_Plugs
TWR.2A.6.02.01.001 | Measure_Plug
TWR.2A.6.02.01.002 | Hydro_Plug
TWR.2A.6.02.02.000 | Injector_Plugs
TWR.2A.6.02.02.001 | Injector_Plug
TWR.2A.6.02.02.002 | Plug_Hold
 | Assembly 3
COTS - MECHANICAL | DIN 934 M8 | 10
 | Part 2 | 89
 | Part 3
TWR.2A.7.00.00.000 | Technology
 | Assembly 1
 | Part 1
 | Part 2
 | Part 3
TWR.2A.7.02.00.000 | Nozzle_Technology
TWR.2A.7.02.00.001 | Nozzle_Body_Blank
TWR.2A.7.02.00.002 | Insert_Blank
TWR.2A.7.03.00.000 | Grain_Prints
TWR.2A.7.03.00.001 | Print_Top
TWR.2A.7.03.00.002 | Print_Bottom

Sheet: COTS - MECHANICAL
Name | Material | Part per Rocket | Parts we have | Location | Theoretical mass [g] | Status | Net Price [pln/pcs] | Gross price [pln/pcs] | The Contractor | Comment
1-SG-006-2-WR513_quick_connect_male |  | 1
BN_1054_M2 |  | 14
BN_1054_press_in_threaded_inserts_M3_Brass |  | 6
D_Sub_Jack_Screw_M3 |  | 2
DIN 934 M8 |  | 10
DIN_439_M16 |  | 1
DIN_444_M5x50 |  | 5
DIN_580_M6 |  | 1
DIN_582_M16 |  | 1
DIN_7500_M3x8 |  | 10
DIN_7985_M2x10 |  | 4
DIN_7985_M2x5 |  | 4
DIN_7985_M2X8 |  | 6
DIN_912_M2x3 |  | 1
DIN_912_M3x10 |  | 52
DIN_914_M3x8 |  | 12
DIN_933_M3x29 |  | 4
DIN_933_M6x70 |  | 4
DIN_934_M2 |  | 22
DIN_965_M2_16 |  | 8
DN 1212 HD ES |  | 1
DN 1214 HD |  | 1
ISO 10642 M4x12 |  | 16
ISO 4032 M2 nut |  | 4
ISO 4762 M2x6 screw |  | 4
ISO_10642_M3x10 |  | 66
ISO_10642_M3x16 |  | 4
ISO_10642_M3x6 |  | 40
ISO_10642_M3x8 |  | 2
ISO_10642_M4x12 |  | 14
ISO_10642_M4x8 |  | 8
ISO_1207_M3x8_Polymide |  | 4
ISO_4014_M8x40 |  | 1
ISO_4014_M8x40_Polymide |  | 2
ISO_4027_M2x2_5 |  | 2
ISO_4032_M16 |  | 2
ISO_4032_M2 |  | 107
ISO_4032_M3 |  | 189
ISO_4032_M4 |  | 36
ISO_4032_M5 |  | 2
ISO_4032_M6 |  | 5
ISO_4032_M8 |  | 1
ISO_4036_M2.5 |  | 16
ISO_4762_M2x10 |  | 20
ISO_4762_M4x25 |  | 2
ISO_7045_M2x10 |  | 14
ISO_7045_M2x8 |  | 23
ISO_7046_M4x6 |  | 8
ISO_7047_M2x5 |  | 8
ISO_7089_16 |  | 3
ISO_7089_3 |  | 2
ISO_7089_4 |  | 12
ISO_7089_5 |  | 4
ISO_7089_8 |  | 2
ISO_7089_Washer_5x10 |  | 24
ISO_7379_M4x8 Screw |  | 12
M16_rod_long |  | 1
M16_rod_small |  | 1
o-ring_1x18_nbr |  | 2
o-ring_1x18_nbr_v2 x 2 |  | 2
O-ring_fi18xfi1_viton |  | 2
Screw_Uni_9817_M3x16 |  | 6
Threaded_rod_M2x24 |  | 3
UNI_5931_M2x10 |  | 6
UNI_5931_M2x12 |  | 12
UNI_5931_M2x6 |  | 4
UNI_5931_M2x8 |  | 2
UNI_6107_M2.5x14 |  | 16

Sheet: COTS - ELECTRONICS
Name | Part per Rocket | Parts we have | Location | Theoretical mass [g] | Status | Net Price [pln/pcs] | Gross price [pln/pcs] | The Contractor | Comment
AltusMetrum_TeleMega | 1
JC_ANTENNA_GPS-MMCX-B | 1
SR_PASSIVES_433M-ANT401 | 2
Turnigy_500mAh_2S_20C_7.4V_Lipo_Pack | 6
Gens_Ace_450mAh_7.4V_30C_SOARING_JST-SYP | 1
Gens_Ace_450mAh_11.1V_30C_SOARING_JST-SYP | 1
Akyga_Li-Pol_560mAh_1S_3.7V | 1
GPX_Extreme_800mAh_11.1V_40C | 2
EHAO_900mAh_3.7V_Li_po_Rechargeable_Battery_JST | 1
TE_Connectivity_D-Sub_Standard_Connectors_9P_PLUG_HOUSING | 1
Raspberry_Cam_v2 | 2
Keystone_18650_battery_holder | 2
Battery_Li_Ion_18650 | 4
N20_DC_motor | 4
Potentiometer_T910X | 4
APRS transmitter | 4
GP2Y1014AU0F | 2
camera(of which i dont know anything about) | 2
LiPol_1S_500mAh | 2
thermoknife_RTS-01-5A | 2 |  |  |  | 2
Camera_Waveshare_HD_G_OV5647 | 2
Camera_connection_board | 1
Rasberry_pi_zero | 2
Li-Pol_Redox_1300mAh_30C_3S_11.1V | 1
Camera_extension_board | 1
SWC_switcch_board | 1

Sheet: IN-HOUSE MANUFACTURING
Part number (if applicable) | Part name | Image | Manufacturing documentation | Average mass | Production time | People needed | Comments
TWR.1A.0.00.00.000 | Twardowsky
TWR.1A.1.00.00.000 | Nosecone
TWR.1A.1.01.00.000 | Cone_body
TWR.1A.1.01.00.001 | Cone_parabole |  |  | 728.9 |  | 2 | Laminated
TWR.1A.1.02.00.000 | Nosecone_electronics
TWR.1A.1.02.01.000 | Electronics_stack
TWR.1A.1.02.01.005 | Threaded_M3_rod |  |  | 4,2 g |  | 1 | Threed from steel rod, 4 times in Electronics_stack
TWR.1A.1.02.01.006 | Stack_distance_1 |  |  | 0.8 |  | 1 | 3D printed, 4 times in Electronics_stack
TWR.1A.1.02.01.007 | Stack_distance_2 |  |  | 0.6 |  | 1 | 3D printed, 12 times in Electronics_stack
TWR.1A.1.02.01.008 | Stack_distance_3 |  |  | 0.4 |  | 1 | 3D printed, 4 times in Electronics_stack
TWR.1A.1.02.00.002 | Mounting_plate_1 |  |  | 212 |  | 1 | Cut from plexi
TWR.1A.1.02.00.003 | Mounting_plate_2 |  |  | 201 |  | 1 | Cut from plexi
TWR.1A.1.02.00.004 | Distance_bolt |  |  | 1.6 |  | 1 | 3D printed, 4 times in Nosecone_electronics
TWR.1A.1.02.00.006 | Turnigy_500mAh_2S_20C_7.4V_batteries_holder1 |  |  | 0.7 |  | 1 | 3D printed, 2 times in Nosecone_electronics
TWR.1A.1.02.00.007 | Turnigy_500mAh_2S_20C_7.4V_batteries_holder_down1 |  |  | 2 |  | 1 | 3D printed, 2 times in Nosecone_electronics
TWR.1A.1.02.00.008 | GPS_base |  |  | 12 |  | 1 | 3D printed
TWR.1A.1.02.00.009 | GPS_holder |  |  | 2 |  | 1 | 3D printed
TWR.1A.1.02.00.010 | Antenna_holder |  |  | 0.8 |  | 1 | 3D printed, 2 times in Nosecone_electronics
TWR.1A.1.02.00.012 | Raspberry_distance_1 |  |  | 0.2 |  | 1 | 3D printed, 8 times in Nosecone_electronics
TWR.1A.1.02.00.013 | Raspberry_distance_2 |  |  | 0.1 |  | 1 | 3D printed, 16 times in Nosecone_electronics
TWR.1A.1.02.00.014 | EHAO_900mAh_3.7V_batteries_holder |  |  | 0.6 |  | 1 | 3D printed
TWR.1A.1.02.00.015 | TeleMega_dystance |  |  | 0.1 |  | 1 | 3D printed, 4 times in Nosecone_electronics
TWR.1A.1.02.00.016 | D-Sub_holder |  |  | 0.8 |  | 1 | 3D printed
TWR.1A.1.02.00.017 | GPX_Extreme_800maH_11V_batteries_holder |  |  | 1.9 |  | 1 | 3D printed, 2 times in Nosecone_electronics
TWR.1A.1.02.00.018 | EHAO_900mAh_3.7V_batteries_holder_down |  |  | 1.6 |  | 1 | 3D printed
TWR.1A.1.02.00.019 | GPX_Extreme_800maH_11V_batteries_holder_down |  |  | 4.5 |  | 1 | 3D printed, 2 times in Nosecone_electronics
TWR.1A.1.02.00.020 | Turnigy_500mAh_2S_20C_7.4V_batteries_holder_down2 |  |  | 1.8 |  | 1 | 3D printed, 4 times in Nosecone_electronics
TWR.1A.1.02.00.021 | Turnigy_500mAh_2S_20C_7.4V_batteries_holder2 |  |  | 0.6 |  | 1 | 3D printed, 4 times in Nosecone_electronics
TWR.1A.1.02.00.022 | Akyga_Li-Pol_560mAh_1S_3.7V_batteries_holder |  |  | 0.5 |  | 1 | 3D printed
TWR.1A.1.02.00.023 | Akyga_Li-Pol_560mAh_1S_3.7V_batteries_holder_down |  |  | 1.5 |  | 1 | 3D printed
TWR.1A.1.02.00.024 | Gens_Ace_450mAh_11.1V_30C_SOARING_batteries_holder |  |  | 0.7 |  | 1 | 3D printed
TWR.1A.1.02.00.025 | Gens_Ace_450mAh_11.1V_30C_SOARING_batteries_holder_down |  |  | 3.1 |  | 1 | 3D printed
TWR.1A.1.02.00.026 | Gens_Ace_450mAh_7.4V_30C_SOARING_batteries_holder |  |  | 0.7 |  | 1 | 3D printed
TWR.1A.1.02.00.027 | Gens_Ace_450mAh_7.4V_30C_SOARING_batteries_holder_down |  |  | 2.6 |  | 1 | 3D printed
TWR.1A.1.02.00.028 | GPX_Extreme_800maH_11V_batteries_holder |  |  | 1.9 |  | 1 | 3D printed
TWR.1A.1.02.00.017 | Threaded_M3_rod |  |  | 4.2 |  |  | Threed from steel rod, 4 times in Nosecone_electronics
TWR.1A.2.00.00.000 | Payload
TWR.1A.2.02.00.000 | CanSat1
TWR.1A.2.02.00.001 | Upper_shell |  |  | 30g |  | 1 | 3D printed
TWR.1A.2.02.00.002 | Lower_shell |  |  | 43g |  | 1 | 3D printed
TWR.1A.2.02.00.003 | Main_plate |  |  | 35g |  | 1 | 3D printed
TWR.1A.2.02.00.004 | Spool |  |  | 1g |  | 1 | 3D printed, need 2 per cansat
TWR.1A.2.02.00.005 | Bracket_motor |  |  | 3g |  | 1 | 3D printed, need 2 per cansat
TWR.1A.2.02.00.007 | Spacer_sleeve |  |  | 0.3g |  | 1 | 3D printed,need 4 per cansat
TWR.1A.2.03.00.000 | CanSat 2
TWR.1A.2.03.00.001 | Shell |  |  | 120g |  | 1 | 3D printed
TWR.1A.2.03.00.002 | shell_cover |  |  | 19.5g |  | 1 | 3D printed
TWR.1A.2.03.00.003 | Tube |  |  | 0.5g |  | 1 | 3D printed
TWR.1A.2.03.00.004 | Air_sensor_holder |  |  | 0.5g |  | 1 | 3D printed
TWR.1A.2.03.00.005 | battery_holder |  |  | 50g |  | 1 | 3D printed
TWR.1A.2.03.00.006 | holder_PCB |  |  | 1.5g |  | 1 | 3D printed
TWR.1A.3.00.00.000 | Recovery_system
TWR.1A.4.00.00.000 | Propulsion_system
TWR.1A.5.00.00.000 | GSE
TWR.1A.6.00.00.000 | Test_equipment
TWR.1A.7.00.00.000 | Technology
OTHER

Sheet: REVISIONS
Date | Author | List of changes
2020-11-12 | Dominika Pytlak | Created document
2020-11-14 | Mateusz Krasuski | Deleted cards "Standardized elements", "Electronics" and "Others". Changed card "Mechanical elements" to "BOM". Changed instruction. Added cards "COTS -MECHANICAL", "COTS - ELECTRICAL" and "REVISIONS"
2020-12-04 | Dominika Pytlak | Added COTS to card "BOM" Recovery System assembly
2021-01-07 | Bartosz Kościanek | Aesthetic changes
2021-03-11 | Tobiasz Moll | Added IN-HOUSE MANUFACTURING card, modified instruction
18.03.2021 | Bartosz Źrebiec | added COTS and some parts to feeding system and fairing
2021-10-12 | Tobiasz Moll | Added parts to BOM and COTS from CES from Payload System and updated Cansats Bom and COTS
2021-10-23 | Tobiasz Moll | CES update
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

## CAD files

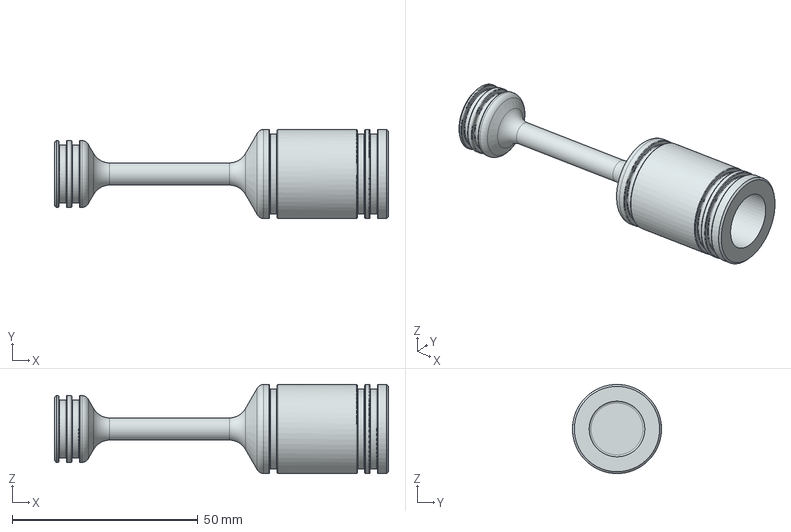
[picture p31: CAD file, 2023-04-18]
02-Drafts/TWR.2A.4_Engine/TWR.2A.4.02_Main_valve/TWR.2A.4.02.01.002_main_valve_piston.stp
90.0 x 24.0 x 24.0 mm

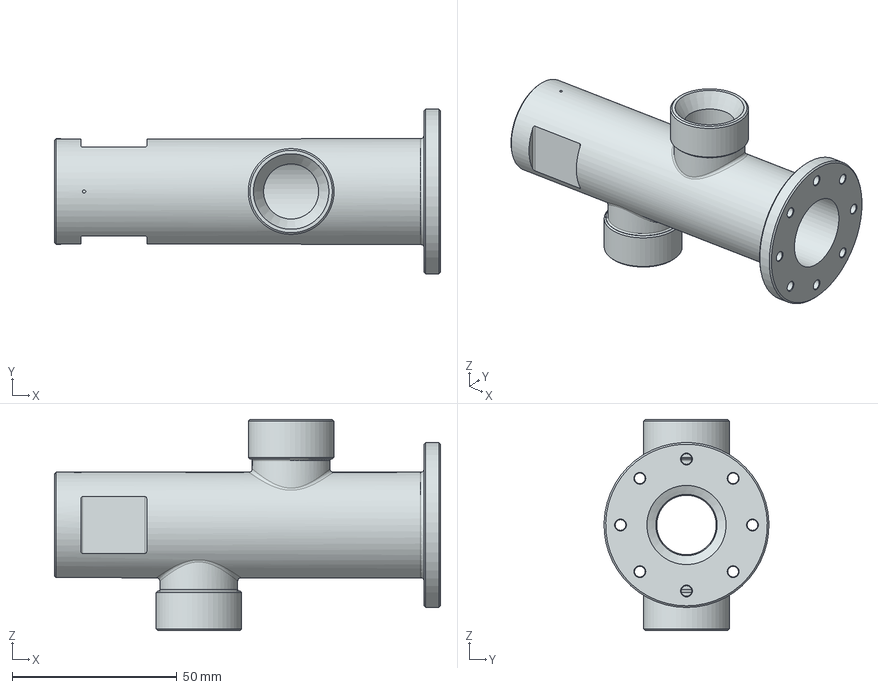
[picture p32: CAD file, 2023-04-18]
02-Drafts/TWR.2A.4_Engine/TWR.2A.4.02_Main_valve/TWR.2A.4.02.01.001_main_valve_body.stp
117.0 x 50.0 x 64.0 mm

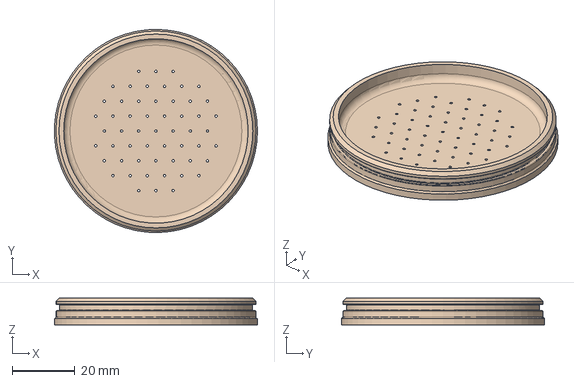
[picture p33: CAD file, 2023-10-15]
02-Drafts/TWR.2A.4_Engine/TWR.1A.4.03.03.002_Showerhead/TWR.1A.4.03.03.002_Showerhead3.stp
65.0 x 65.0 x 8.50 mm

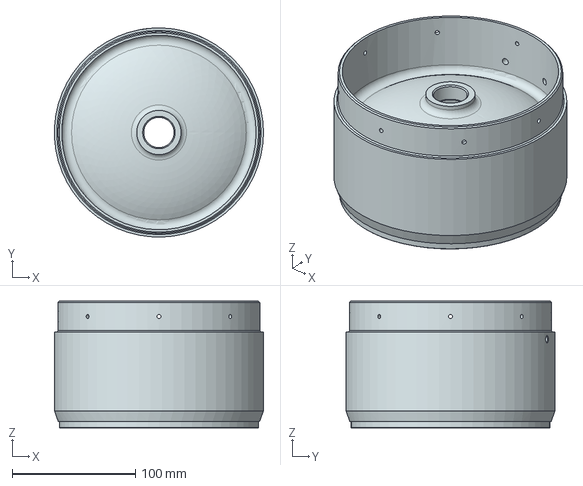
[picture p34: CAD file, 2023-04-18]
02-Drafts/TWR.2A.4_Engine/TWR.2A.4.01_Tank/TWR.2A.4.01.00.002_tank_end_bottom.stp
169.9 x 169.9 x 103.0 mm

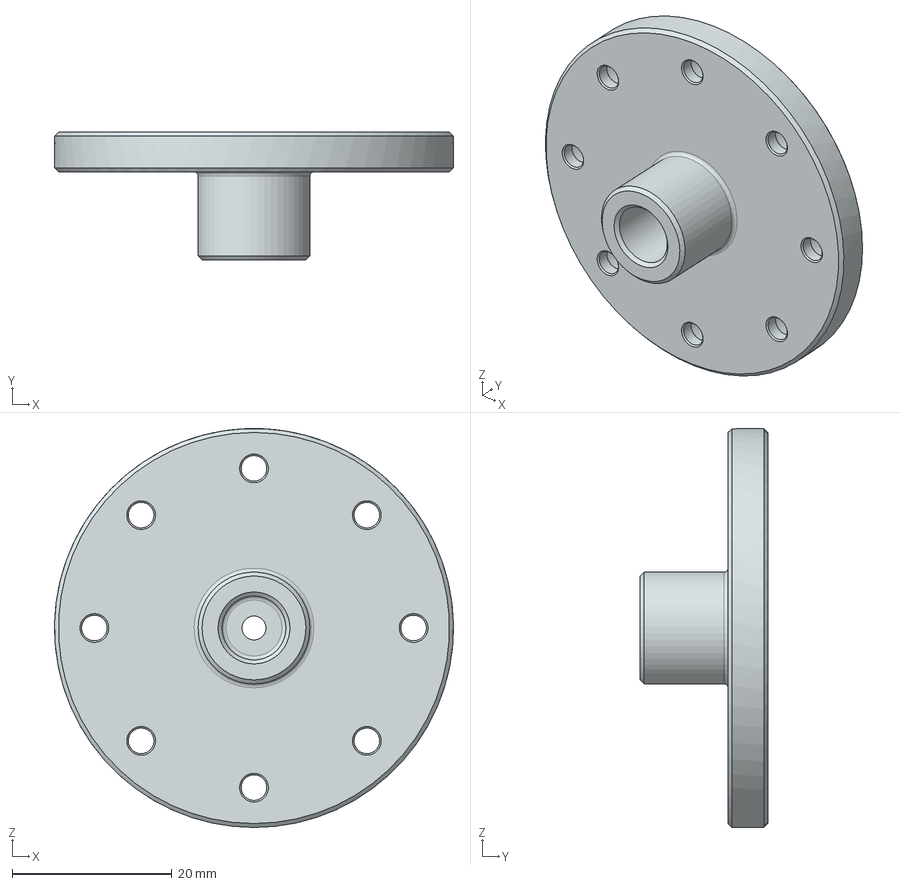
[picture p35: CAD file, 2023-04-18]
02-Drafts/TWR.2A.4_Engine/TWR.2A.4.02_Main_valve/TWR.2A.4.02.01.003_pyro_charge_closing.stp
50.0 x 16.0 x 50.0 mm

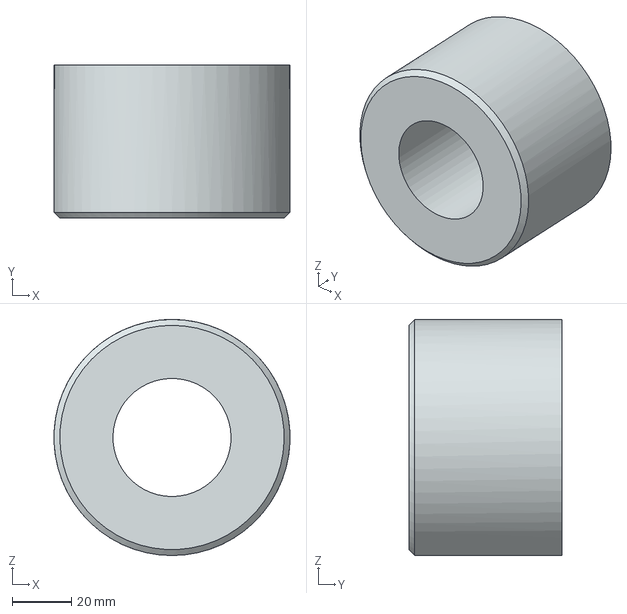
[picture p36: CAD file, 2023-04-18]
02-Drafts/TWR.2A.4_Engine/TWR.2A.4.03_Combustion_chamber/TWR.2A.4.03.01_Nozzle/TWR.2A.4.03.01.005_nozzle_insert_prefab.stp
80.0 x 52.0 x 80.0 mm

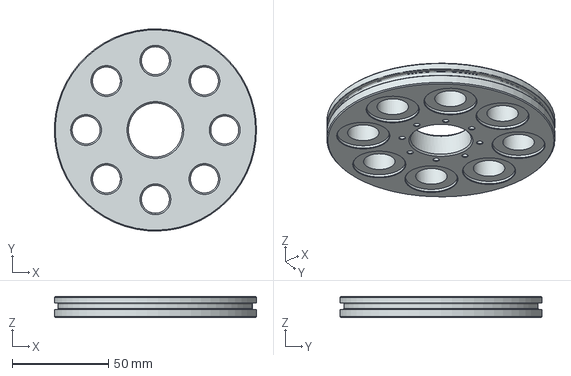
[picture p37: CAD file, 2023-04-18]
02-Drafts/TWR.2A.4_Engine/TWR.2A.4.03_Combustion_chamber/TWR.2A.4.03.02_Plug/TWR.2A.4.03.02.003_adaptive_plate.stp
104.9 x 105.0 x 11.0 mm

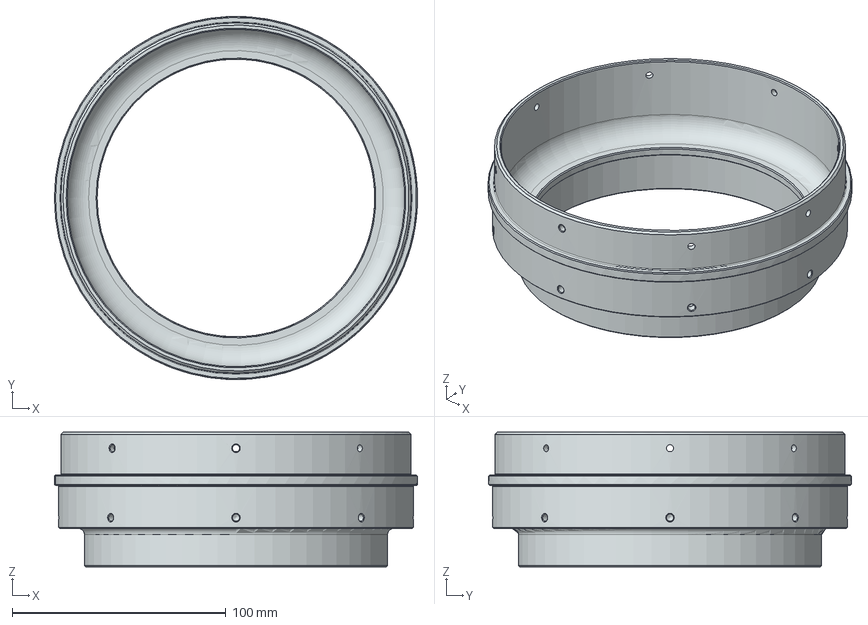
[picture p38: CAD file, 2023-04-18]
02-Drafts/TWR.2A.4_Engine/TWR.2A.4.04_Intersection/TWR.2A.4.04.00.003_Intersection_Insert.stp
170.0 x 169.9 x 63.0 mm

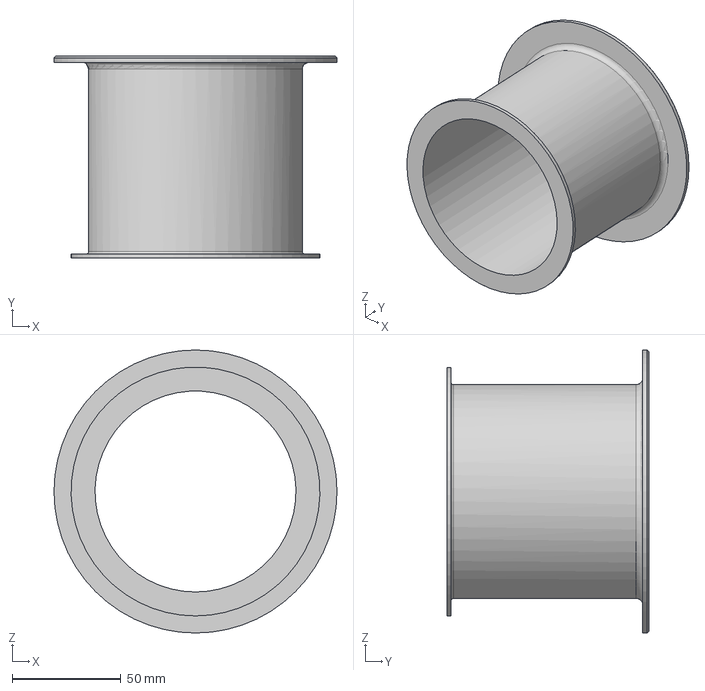
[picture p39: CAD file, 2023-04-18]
02-Drafts/TWR.2A.4_Engine/TWR.2A.4.03_Combustion_chamber/TWR.2A.4.03.01_Nozzle/TWR.2A.4.03.02.001_Nozzle_Body.stp
130.0 x 93.0 x 130.0 mm

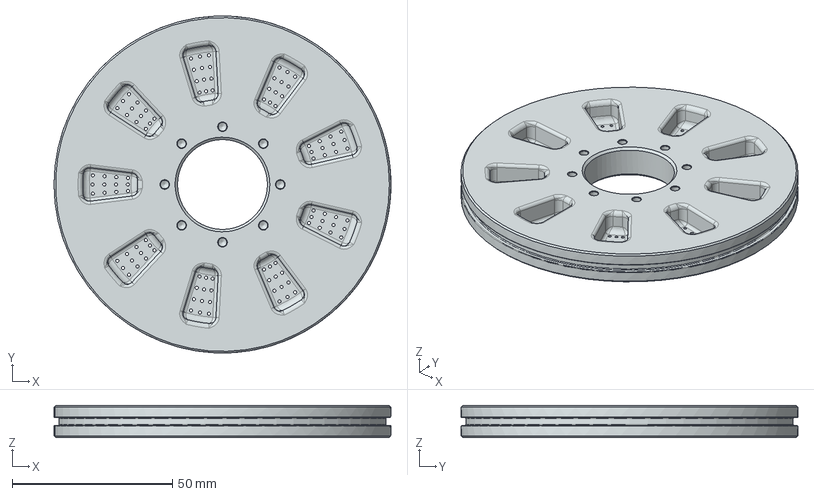
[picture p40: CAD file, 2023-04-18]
02-Drafts/TWR.2A.4_Engine/TWR.2A.4.03_Combustion_chamber/TWR.2A.4.03.02_Plug/TWR.2A.4.03.02.006_showerhead_injector.stp
105.0 x 105.0 x 10.0 mm

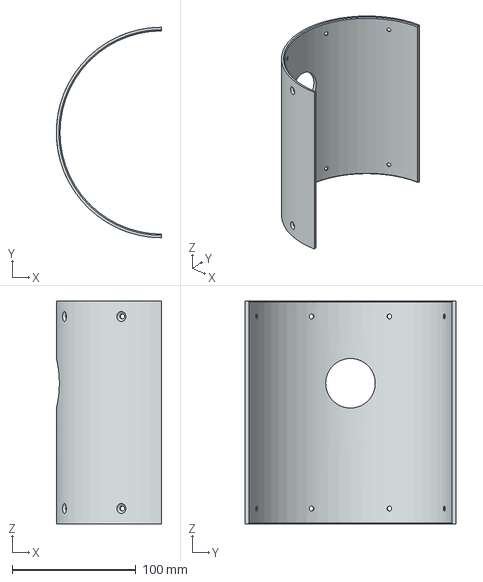
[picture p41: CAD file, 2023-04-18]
02-Drafts/TWR.2A.4_Engine/TWR.2A.4.04_Intersection/TWR.2A.4.04.00.002_Intersection_B.stp
85.0 x 170.0 x 180.0 mm

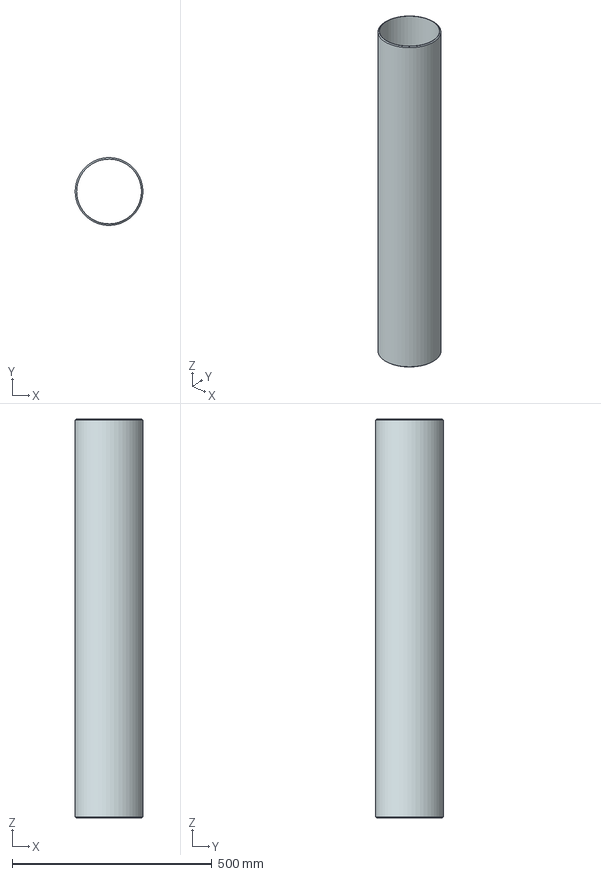
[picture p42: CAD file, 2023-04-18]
02-Drafts/TWR.2A.4_Engine/TWR.2A.4.01_Tank/TWR.2A.4.01.00.001_tank_body.stp
169.8 x 169.9 x 1000.0 mm

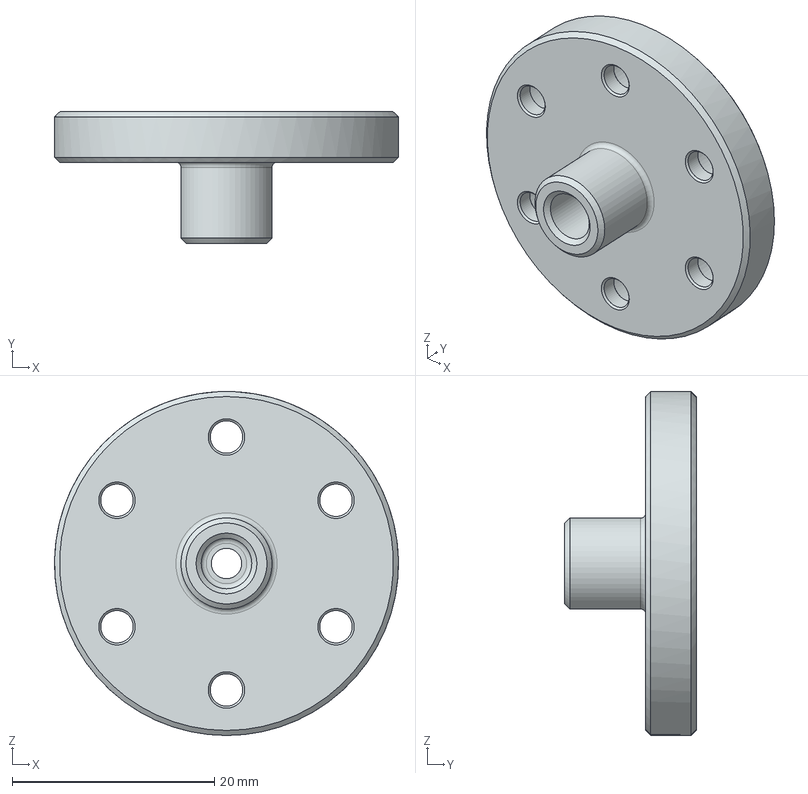
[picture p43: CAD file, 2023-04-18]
02-Drafts/TWR.2A.4_Engine/TWR.2A.4.02_Main_valve/TWR.2A.4.02.01.004_pyro_charge_opening.stp
34.0 x 13.0 x 34.0 mm

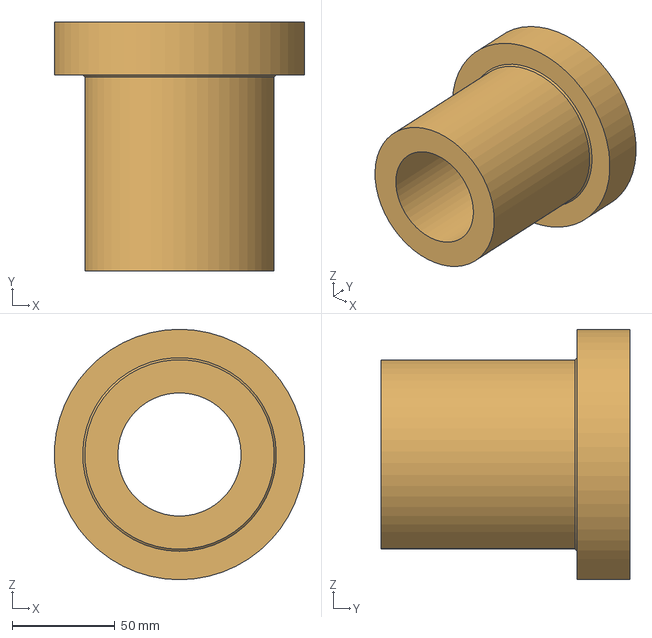
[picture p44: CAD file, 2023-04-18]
02-Drafts/TWR.2A.4_Engine/TWR.2A.4.03_Combustion_chamber/TWR.2A.4.03.01_Nozzle/TWR.2A.4.03.01.004_nozzle_insulation_prefab.stp
121.8 x 121.5 x 122.0 mm

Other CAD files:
02-Drafts/TWR.2A.4_Engine/TWR.2A.4.01_Tank/TWR.2A.4.01.00.002_tank_end_top.stp
02-Drafts/TWR.2A.4_Engine/TWR.2A.4.03_Combustion_chamber/TWR.2A.4.03.02_Plug/TWR.2A.4.03.02.004_swirl_element-TWR2.stp
02-Drafts/TWR.2A.4_Engine/TWR.2A.4.04_Intersection/TWR.2A.4.04.00.001_Intersection_A.stp
02-Drafts/TWR.2A.4_Engine/TWR.2A.4.03_Combustion_chamber/TWR.2A.4.03.02_Plug/TWR.2A.4.03.02.007_igniter_nozzle.stp
01-Model/01-Rocket/COTS/Mechanical/Bearings/ISO_2795_3_5x6x3.prt
01-Model/01-Rocket/COTS/Mechanical/Bearings/R0443_size15_stp.prt
01-Model/01-Rocket/COTS/Mechanical/Bearings/flanged_bushing_pcmf_pcmf_060804_e.stp
01-Model/01-Rocket/COTS/Mechanical/Bearings/flanged_bushing_pcmf_pcmf_060804_e_stp.prt
01-Model/01-Rocket/COTS/Mechanical/Bearings/skf_flanged_bushing_psmf_psmf_050905_a51_stp.prt
01-Model/01-Rocket/COTS/Mechanical/Bearings/skf_straight_bushing_pcm_pcm_050705_e_stp.prt
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

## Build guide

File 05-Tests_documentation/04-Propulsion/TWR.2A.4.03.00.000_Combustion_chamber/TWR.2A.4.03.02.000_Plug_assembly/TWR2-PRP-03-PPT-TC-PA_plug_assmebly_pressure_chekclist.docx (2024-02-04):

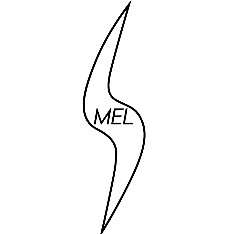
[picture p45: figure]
Obraz zawierający obiekt, lampa Opis wygenerowany automatycznie

Main author: | | Jakub Tyszkiewicz | Co- author(s): | Bartosz Hyży
Date: | | 30.01.2024
Number of pages: | | 7

Pressure proof test of plug assembly

Checklist

The following document provides a checklist of conducting a pressure proof test of plug assembly. In order to get more familiar with plug integration, see document TWR2_plug_integration_procedure.

Page intentionally left blank

PROCEDURES CHECKLIST
Date (YYYY-MM-DD): | | | | | People responsible for the test:
Time of procedure initiation (HH:MM): | | | | | Time of procedure completion (HH:MM):
Location: 011 | | | | | Model of the pump used:
Tested component: TWR.2A.4.03.02.000_Plug_assembly | | | | | Number:
Maximum pressure during work: 90 bar | | | | | Work time: 20 seconds
Pressure obtained: | | Time elapsed after reaching maximum pressure: | | | Pressure after elapsed time: | Confirmed leakage rate: | | Result:
# | Time of activity | | Local time | Status | Activity | | Comments

1. | | | | [ ] | Integrate the plug assembly according to document TWR2_plug_integration_procedure using DIN 908 M12x1 stoppers instead of swirl injectors.
2. | | | | [ ] | Depending on the hydraulic couplings available, seal the main 1" hydraulic outlet from the plug or the outlet for the pressure sensor before injection plate (tube adapter closer to the axis of the plug). | | Remember to use silicone grease on the threads and flat gaskets, and teflon tape where the use of flat gaskets is not possible.
3. | | | | | Pour water into the vessel thus created, until its full. | | Depending on pump producer recommendation, use distilled water as a medium to build-up pressure.
3. | | | | | Screw the hydraulic interface from the pump using the hydraulic couplings selected for this purpose to the plug hydraulic interface left available.
| | | | | Wipe all leftover water on the plugs and combustion chamber body surface using paper towels.
3. | | | | [ ] | Make sure no one is standing near the plug or in the axis of the hydraulic couplings.
4. | | | | [ ] | Wear safety goggles and headphones.
5. | | | | [ ] | Use the pump to build-up desired pressure level.
6. | | | | [ ] | Once the desired system pressure has been reached, wait a preset amount of time, observing the pressure gauge at the pump. Note the changes in pressure values over time.
7. | | | | [ ] | Once the set time has passed, carefully release the pressure using the pump valve. Disassemble the system.

Notes:

No of measurement | Time passed from beginning of test | Current pressure
1
2
3
4

Legible signatures of people responsible for the test:

This document and the information thereon is the property of Students’ Space Association and its contents can only be used by associated members and authorized individuals. STUDENTS’ SPACE ASSOCIATION Pressure proof test of plug assembly

STUDENTS’ SPACE ASSOCIATION Pressure proof test of plug assembly This document and the information thereon is the property of Students’ Space Association and its contents can only be used by associated members and authorized individuals.

Date: 30.01.2024 Page/Total pages: 1/2

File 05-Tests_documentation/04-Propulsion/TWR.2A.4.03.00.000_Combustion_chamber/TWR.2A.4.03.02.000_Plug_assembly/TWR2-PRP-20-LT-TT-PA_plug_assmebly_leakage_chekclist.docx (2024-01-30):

Obraz zawierający obiekt, lampa Opis wygenerowany automatycznie

Main author: | | Jakub Tyszkiewicz | Co- author(s): | Bartosz Hyży
Date: | | 30.01.2024
Number of pages: | | 7

Leakage test of plug assembly

Checklist

The following dokument provides a checklist of conducting a leakage test of plug assembly. In order to get more familiar with plug integration, see document TWR2_plug_integration_procedure.

Page intentionally left blank

PROCEDURES CHECKLIST
Date (YYYY-MM-DD): | | | | | People responsible for the test:
Time of procedure initiation (HH:MM): | | | | | Time of procedure completion (HH:MM):
Location: 011 | | | | | Model of the pump used:
Tested component: TWR.2A.4.03.02.000_Plug_assembly | | | | | Number:
Maximum pressure during work: 8 bar | | | | | Work time: 20 seconds
Pressure obtained: | | Time elapsed after reaching maximum pressure: | | | Pressure after elapsed time: | Confirmed leakage rate: | | Result:
# | Time of activity | | Local time | Status | Activity | | Comments

1. | | | | [ ] | Integrate the plug assembly according to document TWR2_plug_integration_procedure using DIN 908 M12x1 stoppers instead of swirl injectors.
2. | | | | [ ] | Depending on the hydraulic couplings available, seal the main 1" hydraulic outlet from the plug or the outlet for the pressure sensor before injection plate (tube adapter closer to the axis of the plug). Screw the hose from the compressor using the hydraulic couplings selected for this purpose to the hydraulic interface left available. | | Remember to use silicone grease on the threads and flat gaskets, and teflon tape where the use of flat gaskets is not possible.
3. | | | | [ ] | Make sure no one is standing near the plug or in the axis of the hydraulic couplings
4. | | | | [ ] | Wear safety goggles and headphones
5. | | | | [ ] | Switch on the compressor and leave it running until the pressure reaches 8 bar, then switch off the compressor.
6. | | | | [ ] | Count down 20 seconds, during which carefully observe the compressor pressure gauge readings.
7. | | | | [ ] | Note the final system pressure.
8. | | | | [ ] | Release the pressure by unscrewing control valve.
9. | | | | [ ] | Disconnect hose from compressor, disintegrate system under test.

Notes:

No of measurement | Time passed from beginning of test | Current pressure
1

Legible signatures of people responsible for the test:

This document and the information thereon is the property of Students’ Space Association and its contents can only be used by associated members and authorized individuals. STUDENTS’ SPACE ASSOCIATION Leakage test of plug assembly

STUDENTS’ SPACE ASSOCIATION Leakage test of plug assembly This document and the information thereon is the property of Students’ Space Association and its contents can only be used by associated members and authorized individuals.

Date: 30.01.2024 Page/Total pages: 1/2

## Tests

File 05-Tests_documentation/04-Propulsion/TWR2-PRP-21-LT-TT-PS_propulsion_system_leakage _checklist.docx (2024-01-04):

Obraz zawierający obiekt, lampa Opis wygenerowany automatycznie

PROCEDURES CHECKLIST
Date (YYYY-MM-DD): | | People responsible for the test:
Time of procedure initiation (HH:MM): | | Time of procedure completion (HH:MM):
Location: | | Model of the pump/compressor used:
Tested component: TWR.2A.4.00.00.000_Propulsion_system | | Number:
Maximum pressure during work: 8 Bar | | Work time: 3 hours
Pressure obtained: | Time elapsed after reaching maximum pressure: | Pressure after elapsed time: | Confirmed leakage rate: | Result:

Legible signatures of people responsible for the test:

Notes:

No of measurement | Time passed from beginning of test | Current pressure
1
2
3
4
5
6

Date: 04.01.2024 Page/Total pages: 1/2

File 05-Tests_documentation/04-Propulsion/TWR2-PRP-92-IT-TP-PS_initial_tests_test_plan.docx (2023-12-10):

Initial tests’ test plan

Twardowsky 2 propulsion

Bartosz Hyży

1. Introduction Within this document, the test plan regarding initial qualification tests of the propulsion system will be presented. Initial qualification tests are understood as tests, that verify readiness of individual subsystems and its elements for functional tests in conditions specified within project requirements. Main goal of this testing phase is to make sure, that assumptions and calculations accepted during mechanical model creation are compliant with reality, particularly with regard to the stress calculation of components and the design of subsystems’ seals. After that phase of testing, the next step is to begin functional tests campaign which consists of cold flow and hot fire tests.

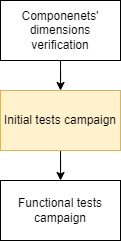
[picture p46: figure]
Obraz zawierający tekst, zrzut ekranu, Czcionka, linia Opis wygenerowany automatycznie

Fig 1. General scheme of qualification test campaign

In order to make sure, that conducted tests will be performed in safe way in accordance with stated requirements, each must be performed in conformance with pre-prepared checklists or test sheets which later have to be stored as a prove, that test took place. For safety reasons, tests involving pyrotechnic materials (gunpowder or solid propellants) require particular attention in the procedure. The integration of pyrotechnic components must always take place under the control of a person experienced in this field.

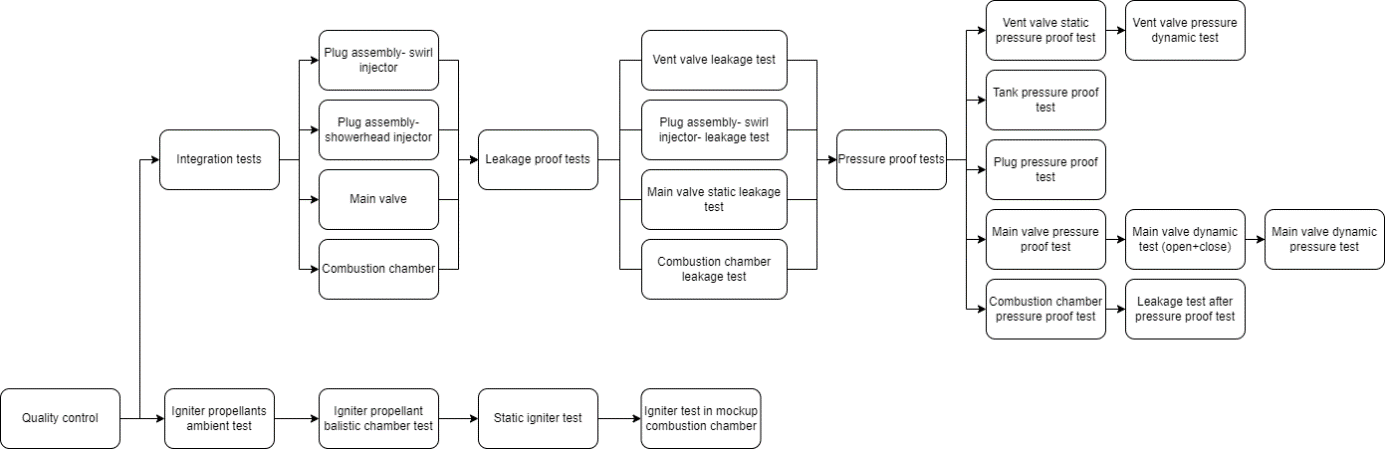
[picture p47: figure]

Fig 2. Initial tests’ campaign

The initial tests consist of several steps, the defined sequence of which must be followed. In addition, due to the different functionality of the subsystems, each has to go through a different route in the verification process. The components and subsystems concerned by the initial tests are listed below:

- Tank
- Main valve
- Vent valve
- Plug assembly
- Combustion chamber

2. Tank

Due to its role in the propulsion system, tank is critical component when it comes to pressure and leakage proof testing procedures. Its durability is determined by the weakest spot in its structure, which is the weld that joints the tank body with its ends. Tank has been welded using simple TIG method, which was chosen for it accessibility and based on previous experiences in Twardowsky project, where welding technology was particularly problematic. Tank leakage test is included in test plan, due to possibility of leakages on weld itself, in case when it was manufactured without cleaning precautions. The test is important because there may be holes in the weld of such small dimensions that pressure tests utilizing water will not detect the leak due to the low compressibility of the medium. For this reason, the fact that the leak test is carried out using air, a compressible gas, is crucial. In the case of target engine operation or when performing cold flow and hot fire tests, the medium that will fill the tank will be partly in the gas phase, which can lead to uncontrolled leakage at the weld.

The test should take place with a gaseous medium, the pressure of which can be easily controlled once the tank is full and can reach maximum pressures in the region of 1 MPa. Carrying out leak tests with higher pressure gases is not recommended for reasons of test safety. A compressible gas, unlike an incompressible liquid (e.g. water), stores much more kinetic energy during compression, which, if the tank is destroyed, can lead to a risk to the life or health of the test participants. At the time of writing, it is assumed as standard, to use a compressor with a maximum operating pressure of 8 bar for this purpose. A compressor with such parameters has been used on numerous occasions during the tests of the Twardowsky 1 engine.

Then, when the tank is found to have passed the test, it should proceed to the pressure test stage. As required, pressure testing of any tank that is part of the rocket must pass the pressure test given a nominal design safety factor of 1.5. The tank's destruction safety factor is 2, but at the time of writing, no tank destruction test is assumed. The nominal tank pressure is 60 bar, so a pressure test must be carried out bringing the tank to a pressure of 90 bar with an accuracy equal to that of the available pressure indicator. For pressure testing the compressed medium is water, preferably demineralized water should be used here to reduce the risk of mineral deposition inside the tank. Water, as a liquid, is an incompressible medium which is preferred for pressure tests. Because of this fact, if a tank is damaged during the test, the kinetic energy that will be imparted to the debris will be much lower than if a gas-filled tank is destroyed. Nevertheless, special safety measures and personal protective equipment, such as safety goggles or protective headphones, must be observed here. According to the requirements set, the predefined pressure must be maintained for 2 times the maximum time allowed for the tank filling process, so the time during which the pressure must be maintained is 180 minutes. During this time, the pressure reading must be checked every 20-30 minutes or so and changes recorded. After this time has elapsed, or if a partial failure of the tank is detected, or if leaks are detected, the set pressure should be released completely before the test participants approach the tank. During the test, the tank should be immobilised and the bottoms protected against damage in case of weld rupture.

3. Main valve

Testing valves is more problematic and requires more steps, than in case of vessels’ tests. The valve qualification process consists of four stages:

- Static leakage test
- Static pressure proof test
- Dynamic test
- Dynamic pressure test

3.1 Static leakage test

Static leakage test is simple and similar to other leakage tests. In this case, the main goal of this test is to verify, weather the sealants for the main valve piston were chosen properly. The test should be performed, when the valve is in the closed position, using gaseous medium. As described in the Tank tests description, the standardized device to produce the pressure here is the compressor with maximal pressure of work of 8 bar. During this test, the valve assembly should be immobilized and nobody should stand in the axis of piston movement.

3.2 Static pressure proof test
After it is confirmed, that the system passed the leakage test, the static pressure proof test should be performed. This test is designed to verify the correctness of the strength simulations of the valve components in the closed position. The test should be carried out at 1.5 times the nominal pressure of the oxidiser in the tank, so the set pressure should be 90 bar. The pressure should be set from the inlet port side with the valve piston in the closed position. The purpose of the test is to verify that the valve can also be used during the entire filling and pressurizing period, so, as in case of tank pressure test, the pressure should be maintained over a period of 180 minutes. Pressure drops during this time should be periodically recorded. As is the case with all pressure tests, here too water should be used as the working medium.

3.3 Dynamic test

The dynamic test of the valve verifies the ability of the valve to change state between closed and open positions. In order to correctly verify the valve operation, at least 5 tests must be carried out for each of the following operating scenarios:

- switching from closed to open position

- switching from open to closed position

- switching from closed to open position and then switching to closed position after approx. 2 seconds

Dynamic tests take place without pressure load. The tests corresponding to all the scenarios listed should be carried out with the system fully integrated. The two pyrotechnic charges (also not activated during the test) should be elaborated in order to verify the risk of damage to the charge during deceleration of the piston movement.

After each test corresponding to the last mentioned scenario, the leaktightness of the valve in the final closed position should additionally be checked.

3.4 Dynamic pressure test

After confirming the valve's ability to operate under unloaded conditions, proceed to performance tests under conditions corresponding to the operating conditions. It is worth mentioning here that the geometry of the main valve piston has been selected in such a way that the pressure of the fluid flowing through the valve generates a force in the direction of the piston movement when it opens. In this context, a pressure value equal to the nominal pressure, i.e. 60 bar, was considered as the worst case of operation during the opening of the valve under pressure. At this pressure, therefore, dynamic tests should be carried out under the valve load. In order to correctly verify the valve operation, at least 5 tests must be carried out for each of the following operating scenario:

- switching from closed to open position

The tests corresponding to this scenario should be carried out with the system fully integrated. The two pyrotechnic charges (also not activated during the test) should be elaborated in order to verify the risk of damage to the charge during deceleration of the piston movement.

4. Vent valve

The vent valve used in the engine design is a COTS ACL brand valve, model E170BBL15. Despite the manufacturer's assurance of the valve's correct operating conditions, additional validation of the valve's operation must be performed. For this purpose, a leakage test and a pressure test of the closed valve position should be carried out. Both tests should be carried out at 2 times the maximum time allowed for filling and pressurising the oxidiser in the tank. Thus, the load for both tests should be held for a period of 180 minutes, with pressure drop values being read cyclically over time during this time. Particular attention should be paid here to the application of the load on the inlet side of the valve. The leak test should be carried out using an air compressor at a maximum pressure of approx. 1 MPa. As with the other leakage tests, it is recommended that the test is carried out using a compressor at a maximum operating pressure of around 8 bar, as was the case with the Twardowsky rocket engine leakage tests. In contrast, the valve pressure test should be carried out at the nominal oxidiser pressure, i.e. 60 bar, using water as the working medium.

5. Plug assembly

In case of plug assembly, a leak test and pressure test should be carried out. Due to the design, both tests should be carried out in the 'swirl injector' configuration of the plug assembly, replacing the injectors themselves with plugs. For practical reasons, the plugs should be sealed by flat washers on the outlet side of the adaptor plate, allowing the system to be sealed without disintegrating the system. The leak test should be carried out using the recommended air compressor at a maximum pressure of 8 bar. The initial pressure test, should be carried out at 45 bar, which is 1.5 times the pressure difference between the expected tank pressure and the engine combustion chamber pressure. The load for both tests should be maintained at 2 times the engine operating time. Thus, the load should be applied over a period of about 20 seconds, with the final pressure noted after this period. The first pressure test here is at a lower pressure than the nominal pressure due to the conditions of the plug during the first cold flow test. Once first cold flow test has taken place, a second pressure test should be carried out by applying a pressure of 90 bar over the same period of time. This procedure is due to the fact that the plug has a relatively low safety factor and its destruction will stop the test campaign by prohibiting functional tests.

6. Combustion chamber

Tests related to the combustion chamber must be performed under conditions different from those for other pressure vessels. This is related to the anisotropicity of the carbon-phenol composite used to construct the chamber and the fact that the combustion chamber bodies are manufactured in the association's workshop. The required burst safety factor of the combustion chamber in this case is 3. Pressure tests in this case should be carried out to a load factor of 2. Therefore, pressure tests in this case should be carried out using a load of 80 bar, due to the maximum expected pressure in the chamber combustion equal to 40 bar when working in the configuration with a swirl injector. Leakage tests should be carried out using the recommended air compressor at a pressure of 8 bar. Both the pressure test and the leakage test should involve applying a load for 20 seconds and noting the final pressure. However, after the pressure test, the tightness test should be performed again to verify that there was no damage to the combustion chamber body during the pressure test. Such tests should be performed each time for each newly manufactured combustion chamber in order to qualify the component for further testing. If finances and time allow, it is also recommended to perform a combustion chamber burst test to determine the actual burst safety factor. However, there is a risk of destruction of test components (including test plugs).

7. Revision

No. | Revisor | Date
1 | Bartosz Hyży | 2023-12-10

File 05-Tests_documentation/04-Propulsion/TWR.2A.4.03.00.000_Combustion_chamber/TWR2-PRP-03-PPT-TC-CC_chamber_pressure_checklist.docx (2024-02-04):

Obraz zawierający obiekt, lampa Opis wygenerowany automatycznie

Main author: | | Michał Banaszak | Co- author(s): | Bartosz Hyży
Date: | | 04.02.2024
Number of pages: | | 7

Pressure proof test of combustion chamber

Checklist

The following document provides a checklist of correctly done pressure tests of combustion chamber. Since the combustion chamber construction is using the same technology as Grot casing, some Grot technological elements are also used here.

Page intentionally left blank

PROCEDURES CHECKLIST
Date (YYYY-MM-DD): | | | | | People responsible for the test:
Time of procedure initiation (HH:MM): | | | | | Time of procedure completion (HH:MM):
Location: 011 | | | | | Model of the pump used:
Tested component: G.1.02.01.000_Casing, G.1.02.00.001_Insulation | | | | | Number:
Maximum pressure during work: 90 Bar (safety factor equal to 2) | | | | | Work time: 20 seconds
Pressure obtained: | | Time elapsed after reaching maximum pressure: | | | Pressure after elapsed time: | Confirmed safety factor: | | Result:
# | Time of activity | | Local time | Status | Activity | | Comments

1. | | | | [ ] | Read the safety rules and the test instruction. Put on protective clothing.
2. | | | | [ ] | Insert element G.1.02.00.001_Insulation in G.1.02.01.000_Casing
3. | | | | [ ] | Seal the orifices of TG.5.02.00.001_Closure_hydro_plug_2 using suitable plugs and flat plumbing washers or Teflon tape.
4. | | | | [ ] | Insert element TG.5.02.00.001_Closure_hydro_plug_2 sealing the connection with o-rings. Make sure that the grooves for the o-rings and the o-rings themselves are coated with silicone grease.
5. | | | | [ ] | Secure the position of the plug by fitting a seger in the groove above it.
6. | | | | [ ] | Pour water into the vessel thus created. The water should reach a level just below the second groove for the seger ring. | | Depending on pump producer recommendation, use distilled water as a medium to build-up pressure.
7. | | | | [ ] | Seal the M5 threaded orifice in the plug using a Teflon-wound screw or a suitable flat gasket. Leave the G1/4 hydraulic outlet open.
8. | | | | [ ] | As with the first plug, also seal the second plug- insulation connection with o-rings, taking care to coat the surface of the o-ring grooves and the o-rings themselves with grease.
9. | | | | [ ] | Secure the position of the second plug by fitting a second seger.
7. | | | | [ ] | Screw the appropriate hydraulic adapters into the G1/4 outlet of the plug so that a pressure pump can be connected to it.
8. | | | | [ ] | Screw the hydraulic adaptor of the pump to the system outlet thus created.
9. | | | | [ ] | Wipe all leftover water on the plugs and combustion chamber body surface using paper towels.
10. | | | | [ ] | Use the pump to build-up desired pressure level.
11. | | | | [ ] | Once the desired system pressure has been reached, wait a preset amount of time, observing the pressure gauge at the pump. Note the changes in pressure values over time.
12. | | | | [ ] | Once the set time has passed, carefully release the pressure using the pump valve. Disassemble the system.

Notes:

No of measurement | Time passed from beginning of test | Current pressure
1
2
3
4
5
6

Legible signatures of people responsible for the test:

This document and the information thereon is the property of Students’ Space Association and its contents can only be used by associated members and authorized individuals. STUDENTS’ SPACE ASSOCIATION Pressure proof test of combustion chamber

STUDENTS’ SPACE ASSOCIATION Pressure proof test of combustion chamber This document and the information thereon is the property of Students’ Space Association and its contents can only be used by associated members and authorized individuals.

Date: 04.02.2024 Page/Total pages: 1/2

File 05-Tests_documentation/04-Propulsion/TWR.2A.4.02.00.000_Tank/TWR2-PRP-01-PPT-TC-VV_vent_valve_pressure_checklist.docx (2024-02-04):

Obraz zawierający obiekt, lampa Opis wygenerowany automatycznie

Main author: | | Pavel Chernenko | Co- author(s): | Bartosz Hyży
Date: | | 06.12.2023
Number of pages: | | 7

Pressure proof test of vent valve

Checklist

The following document provides a checklist of correctly done pressure tests of the oxidizer vent valve. The component is COTS, so the manufacturer provides a specific pressure resistance. However, because of the desire to ascertain the claimed strength and because of the potential for the component to fail as the system is developed, a procedure has been developed to test the pressure strength of the valve.

Page intentionally left blank

PROCEDURES CHECKLIST
Date (YYYY-MM-DD): | | | | | People responsible for the test:
Time of procedure initiation (HH:MM): | | | | | Time of procedure completion (HH:MM):
Location: 011 | | | | | Model of the pump used:
Tested component: TWR.2A.4.01.01.004_electrovalve | | | | | Number:
Maximum pressure during work: 90 Bar | | | | | Work time: 3 hours
Pressure obtained: | | Time elapsed after reaching maximum pressure: | | | Pressure after elapsed time: | Confirmed safety factor: | | Result:
# | Time of activity | | Local time | Status | Activity | | Comments

1. | | | | [ ] | Read the safety rules and the test instruction. Put on protective clothing.
2. | | | | [ ] | Assemble valve according with TWR2_vent_valve_data_sheet including the plastic box with electronics. Make sure to properly assemble sealant. | | Depending on the pump manufacturer's recommendations, use distilled water as a pressure build-up medium.
3. | | | | [ ] | Screw the hydraulic adapters from the inlet side of the valve in such a way that the hydraulic system of the pump can be screwed on. The choice of suitable adapters is arbitrary and depends on the hydraulic interface of the pump. Fill created system with prepared pressure build-up medium. | | Pay particular attention to the correct choice of valve side. Use flat sealing washers coated with silicone grease where possible. For such connections, use grease also on the threads of the adapters. In the rest of connections, use teflon tape.
4. | | | | [ ] | Screw the hydraulic interface of the pump to the valve assembly inlet. If its possible, place the valve vertically to facilitate leak detection by observing the presence of leaking medium.
5. | | | | [ ] | Use a pump to build up the desired pressure.
6. | | | | [ ] | Wait the desired time, noting changes in system pressure (see Notes section).
24. | | | | [ ] | Carefully release the pressure using the safety valve on the pump. Disassemble the system.

Notes:

No of measurement | Time passed from beginning of test | Current pressure
1
2
3
4
5
6

Legible signatures of people responsible for the test:

This document and the information thereon is the property of Students’ Space Association and its contents can only be used by associated members and authorized individuals. STUDENTS’ SPACE ASSOCIATION Pressure proof test of vent valve

STUDENTS’ SPACE ASSOCIATION Pressure proof test of vent valve This document and the information thereon is the property of Students’ Space Association and its contents can only be used by associated members and authorized individuals.

Date: 06.12.2023 Page/Total pages: 1/2

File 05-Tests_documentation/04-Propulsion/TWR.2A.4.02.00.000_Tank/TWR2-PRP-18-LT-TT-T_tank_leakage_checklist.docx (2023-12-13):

Obraz zawierający obiekt, lampa Opis wygenerowany automatycznie

PROCEDURES CHECKLIST
Date (YYYY-MM-DD): | | People responsible for the test:
Time of procedure initiation (HH:MM): | | Time of procedure completion (HH:MM):
Location: 012 | | Model of the pump used:
Tested component: TWR.2A.4.01.00.000_Tank-01 | | Number:
Maximum pressure during work: 87 Bar | | Work time: 1 hour
Pressure obtained: | Time elapsed after reaching maximum pressure: | Pressure after elapsed time: | Confirmed safety factor: | Result:

Legible signatures of people responsible for the test:

Notes:

No of measurement | Time passed from beginning of test | Current pressure
1
2
3
4
5
6

Date: 06.12.2023 Page/Total pages: 1/2

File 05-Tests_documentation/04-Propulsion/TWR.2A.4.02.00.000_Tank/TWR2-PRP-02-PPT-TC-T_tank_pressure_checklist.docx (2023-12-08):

Obraz zawierający obiekt, lampa Opis wygenerowany automatycznie

Main author: | | Pavel Chernenko | Co- author(s): | Bartosz Hyży
Date: | | 06.12.2023
Number of pages: | | 7

Pressure proof test of an oxidizer tank

Checklist

The following dokument provides a checklist of correctly done pressure tests of an oxidizer tank.

Page intentionally left blank

PROCEDURES CHECKLIST
Date (YYYY-MM-DD): | | | | | People responsible for the test:
Time of procedure initiation (HH:MM): | | | | | Time of procedure completion (HH:MM):
Location: 011 | | | | | Model of the pump used:
Tested component: TWR.3.00.00.000_Zbiornik | | | | | Number:
Maximum pressure during work: 90 Bar | | | | | Work time: 3 hours
Pressure obtained: | | Time elapsed after reaching maximum pressure: | | | Pressure after elapsed time: | Confirmed safety factor: | | Result:
# | Time of activity | | Local time | Status | Activity | | Comments

1. | | | | [ ] | Read the safety rules and the test instruction. Put on protective clothing.
2. | | | | [ ] | Gather all materials needed in accordance with the checklist [number of the list of materials checklist]. Check the compliance of the components with their drawings.
3. | | | | [ ] | Make sure that the elements have been cleaned in accordance with the checklist [number of the elements cleaning checklist].
4. | | | | [ ] | Screw pump adapter to the pump itself with proper sealing
5. | | | | [ ] | Put a sealing ring onto the thread of adapter.
6. | | | | [ ] | Screw the plug into the one of the threaded holes.
7. | | | | [ ] | Set the tank with the plug facing down, then fill it with non-mineralized water to the level of second threaded hole.
8. | | | | [ ] | Top up with water using a syringe.
9. | | | | [ ] | Wipe all water on the tank and plugs surface using paper towels.
10. | | | | [ ] | Use proper sealing in the adapter to the tank.
11. | | | | [ ] | Screw the pump into the second of the threaded holes.
12. | | | | [ ] | Check the tightness by moving around the tank.
13. | | | | [ ] | Pressurize the tank to 0,5 MPa.
14. | | | | [ ] | Check for water leaks (especially on the thread). If there are leaks on the thread, apply bigger force and check the sealing rings.
15. | | | | [ ] | If there are no leaks, cover it with bright clothes.
16. | | | | [ ] | Pressurize the tank until a pressure of 90 Bar is reached.
17. | | | | [ ] | After reaching a pressure of 90 Bar, lock the pump and wait for 180 minutes and check on leaks as the pressure is reached and then every 20-30 minutes.
18. | | | | [ ] | Write down the pressure current pressure at every check, the table provided.
19. | | | | [ ] | Pump out the water until the ambient pressure is reached.
20. | | | | [ ] | Take the oxidizer tank out of the container and place it vertically with the hole with pump facing up.
21. | | | | [ ] | Check for water leaks and mark them using a black marker.
22. | | | | [ ] | Unscrew the pump.
23. | | | | [ ] | Pour out water from the tank (water can be used once again in another hydrotest).
24. | | | | [ ] | Remove the plug.

Notes:

No of measurement | Time passed from beginning of test | Current pressure
1
2
3
4
5
6

Legible signatures of people responsible for the test:

This document and the information thereon is the property of Students’ Space Association and its contents can only be used by associated members and authorized individuals. STUDENTS’ SPACE ASSOCIATION Pressure proof test of an oxidizer tank

STUDENTS’ SPACE ASSOCIATION Pressure proof test of an oxidizer tank This document and the information thereon is the property of Students’ Space Association and its contents can only be used by associated members and authorized individuals.

Date: 06.12.2023 Page/Total pages: 1/2

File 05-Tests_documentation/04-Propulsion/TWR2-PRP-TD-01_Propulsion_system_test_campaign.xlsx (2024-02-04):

TESTS |  |  |  |  |  |  | OTHER DOCUMENTS |  |  |  |  | Abbreviations
Test type | Tested component/system | Document | Document number | Author | Approved by | Date | Document | Document name | Author | Approved by | Date
Pressure proof tests | Venting valve | Pressure proof test checklist | TWR2-PRP-01-PPT-TC-VV | Pavel Chernenko |  |  | Pressure proof test safety rules | TWR2-PRP-99-PPT-SR-PS | Bartosz Hyży |  |  | VV | Vent valve
 | Tank | Pressure proof test checklist | TWR2-PRP-02-PPT-TC-T | Pavel Chernenko |  |  | Pyrotechnic safety rules | TWR2-PRP-98-PYR-SR-PS | Bartosz Hyży |  |  | CC | Combustion chamber
 | Combustion chamber | Pressure proof test checklist | TWR2-PRP-03-PPT-TC-CC | Michał Banaszak |  |  | Propulsion system integration procedure | TWR2-PRP-97-G-IP-PS | Bartosz Hyży |  |  | PA | Plug assembly
 | Plug assembly | Pressure proof test checklist | TWR2-PRP-03-PPT-TC-PA | Michał Banaszak |  |  | Cold flow safety rules | TWR2-PRP-96-CF-SR-PS | TBD |  |  | PS | Propulsion system
 | Propulsion system assembly | Pressure proof test checklist | TWR2-PRP-05-PPT-TC-PS | Michał Banaszak |  |  | Igniter manufacturing safety rules | TWR2-PRP-95-M-SR-IGN | Bartosz Hyży | Bartosz Hyży | 2023-12-12 | IGN | Igniter
Igniter tests | Igniter | Manufacturing checklist | TWR2-PRP-06-M-MC-IGN | Bartosz Hyży |  |  | Hot fire test stand integration procedure | TWR2-PRP-94-HF-IP-PS | TBD |  |  | T | Tank
 |  | Igniter elaboration checklist | TWR2-PRP-07-G-IC-IGN | Bartosz Hyży |  |  | Hot fire test safety rules | TWR2-PRP-93-HF-SR-PS | TBD |  |  | MV | Main valve
 |  | Atmosphere combustion testcard | TWR2-PRP-08-AC-TT-IGN | Bartosz Hyży |  |  | Initial tests' test plan | TWR2-PRP-92-IT-TP-PS | Bartosz Hyży
 |  | Atmosphere combustion test report | TWR2-PRP-09-AC-TR-IGN | Bartosz Hyży |  |  | Functional tests' test plan | TWR2-PRP-91-FT-TP-PS | Bartosz Hyży |  |  | PPT | Pressure proof test
 |  | Balistic chamber testcard | TWR2-PRP-10-BC-TT-IGN | Michał Tomporowski |  |  | Tank test plan | TWR2-PRP-90-IT-TP-T | Pavel Chernenko |  |  | M | Manufacturing
 |  | Balistic chamber test report | TWR2-PRP-11-BC-TR-IGN | Michał Tomporowski |  |  | Propulsion system assembly checklist | TWR2-PRP-89-G-IP-PS | Bartosz Hyży |  |  | G | General
 |  | Static igniter test integration checklist | TWR2-PRP-12-SIT-IC-IGN | Michał Tomporowski |  |  | Tank manufacturer documentation | TWR2-PRP-88-M-MD-T | Bartosz Hyży | Bartosz Hyży | 2023-12-11 | AC | Atmosphere combustion test
 |  | Static igniter testcard | TWR2-PRP-13-SIT-TT-IGN | Michał Tomporowski |  |  |  |  |  |  |  | BC | Ballistic chamber test
 |  | Mockup combustion chamber integration checklist | TWR2-PRP-14-MIT-IC-IGN | Bartosz Rylski |  |  | To be created |  |  |  |  | SIT | Static igniter test
 |  | Mockup combustion chamber testcard | TWR2-PRP-15-MIT-TT-IGN | Bartosz Rylski |  |  | Ready for approval |  |  |  |  | MIT | Mockup igniter test
 |  | Mockup combustion chamber test report | TWR2-PRP-16-MIT-TR-IGN | Bartosz Rylski |  |  | Approved |  |  |  |  | LT | Leakage test
Leakage tests | Venting valve | Leakage test checklist | TWR2-PRP-17-LT-TT-VV | Pavel Chernenko |  |  |  |  |  |  |  | DO | Dynamic opening test
 | Tank | Leakage test checklist | TWR2-PRP-18-LT-TT-T | Pavel Chernenko |  |  |  |  |  |  |  | DC | Dynamic closing test
 | Combustion chamber | Leakage test checklist | TWR2-PRP-19-LT-TT-CC | Jakub Tyszkiewicz |  |  |  |  |  |  |  | DOC | Dynamic opening+closing test
 | Plug assembly | Leakage test checklist | TWR2-PRP-20-LT-TT-PA | Jakub Tyszkiewicz |  |  |  |  |  |  |  | DPO | Dynamic opening under pressure
 | Propulsion system assembly | Leakage test checklist | TWR2-PRP-21-LT-TT-PS | Jakub Tyszkiewicz |  |  |  |  |  |  |  | CF | Cold flow test
Main valve tests | Main valve | Main valve integration checklist | TWR2-PRP-22-G-IC-MV | Alicja Kwitek |  |  |  |  |  |  |  | HF | Hot fire test
 |  | Main valve leakage testcard | TWR2-PRP-23-LT-TT-MV | Mikołaj Salamon |  |  |  |  |  |  |  | PYR | Pyrotechnics
 |  | Main valve static pressure test checklist | TWR2-PRP-24-PPT-TC-MV | Mikołaj Salamon |  |  |  |  |  |  |  | IT | Initial tests
 |  | Main valve dynamic opening testcard | TWR2-PRP-25-DO-TT-MV | Alicja Kwitek |  |  |  |  |  |  |  | FT | Functional tests
 |  | Main valve dynamic closing testcard | TWR2-PRP-26-DC-TT-MV | Alicja Kwitek
 |  | Main valve dynamic opening+closing testcard | TWR2-PRP-27-DOC-TT-MV | Alicja Kwitek |  |  |  |  |  |  |  | TC | Test checklist
 |  | Main valve dynamic pressure opening testcard | TWR2-PRP-28-DPO-TT-MV | Alicja Kwitek |  |  |  |  |  |  |  | TT | Testcard
 |  |  |  |  |  |  |  |  |  |  |  | MC | Manufacturing checklist
 |  |  |  |  |  |  |  |  |  |  |  | IC | Integration checklist
 |  |  |  |  |  |  |  |  |  |  |  | TR | Test report
 |  |  |  |  |  |  |  |  |  |  |  | SR | Safety rules
 |  |  |  |  |  |  |  |  |  |  |  | IP | Integration procedure
 |  |  |  |  |  |  |  |  |  |  |  | TP | Test plan
 |  |  |  |  |  |  |  |  |  |  |  | MD | Manufacturer documentation

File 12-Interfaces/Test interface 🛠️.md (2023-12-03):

---
Connections: 
Class:
  - Interface
Type:
  - Mechanical
---
# Description

## How it works

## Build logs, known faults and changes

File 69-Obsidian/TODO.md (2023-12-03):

- [ ] https://github.com/jacopocolo/Penzil/tree/main

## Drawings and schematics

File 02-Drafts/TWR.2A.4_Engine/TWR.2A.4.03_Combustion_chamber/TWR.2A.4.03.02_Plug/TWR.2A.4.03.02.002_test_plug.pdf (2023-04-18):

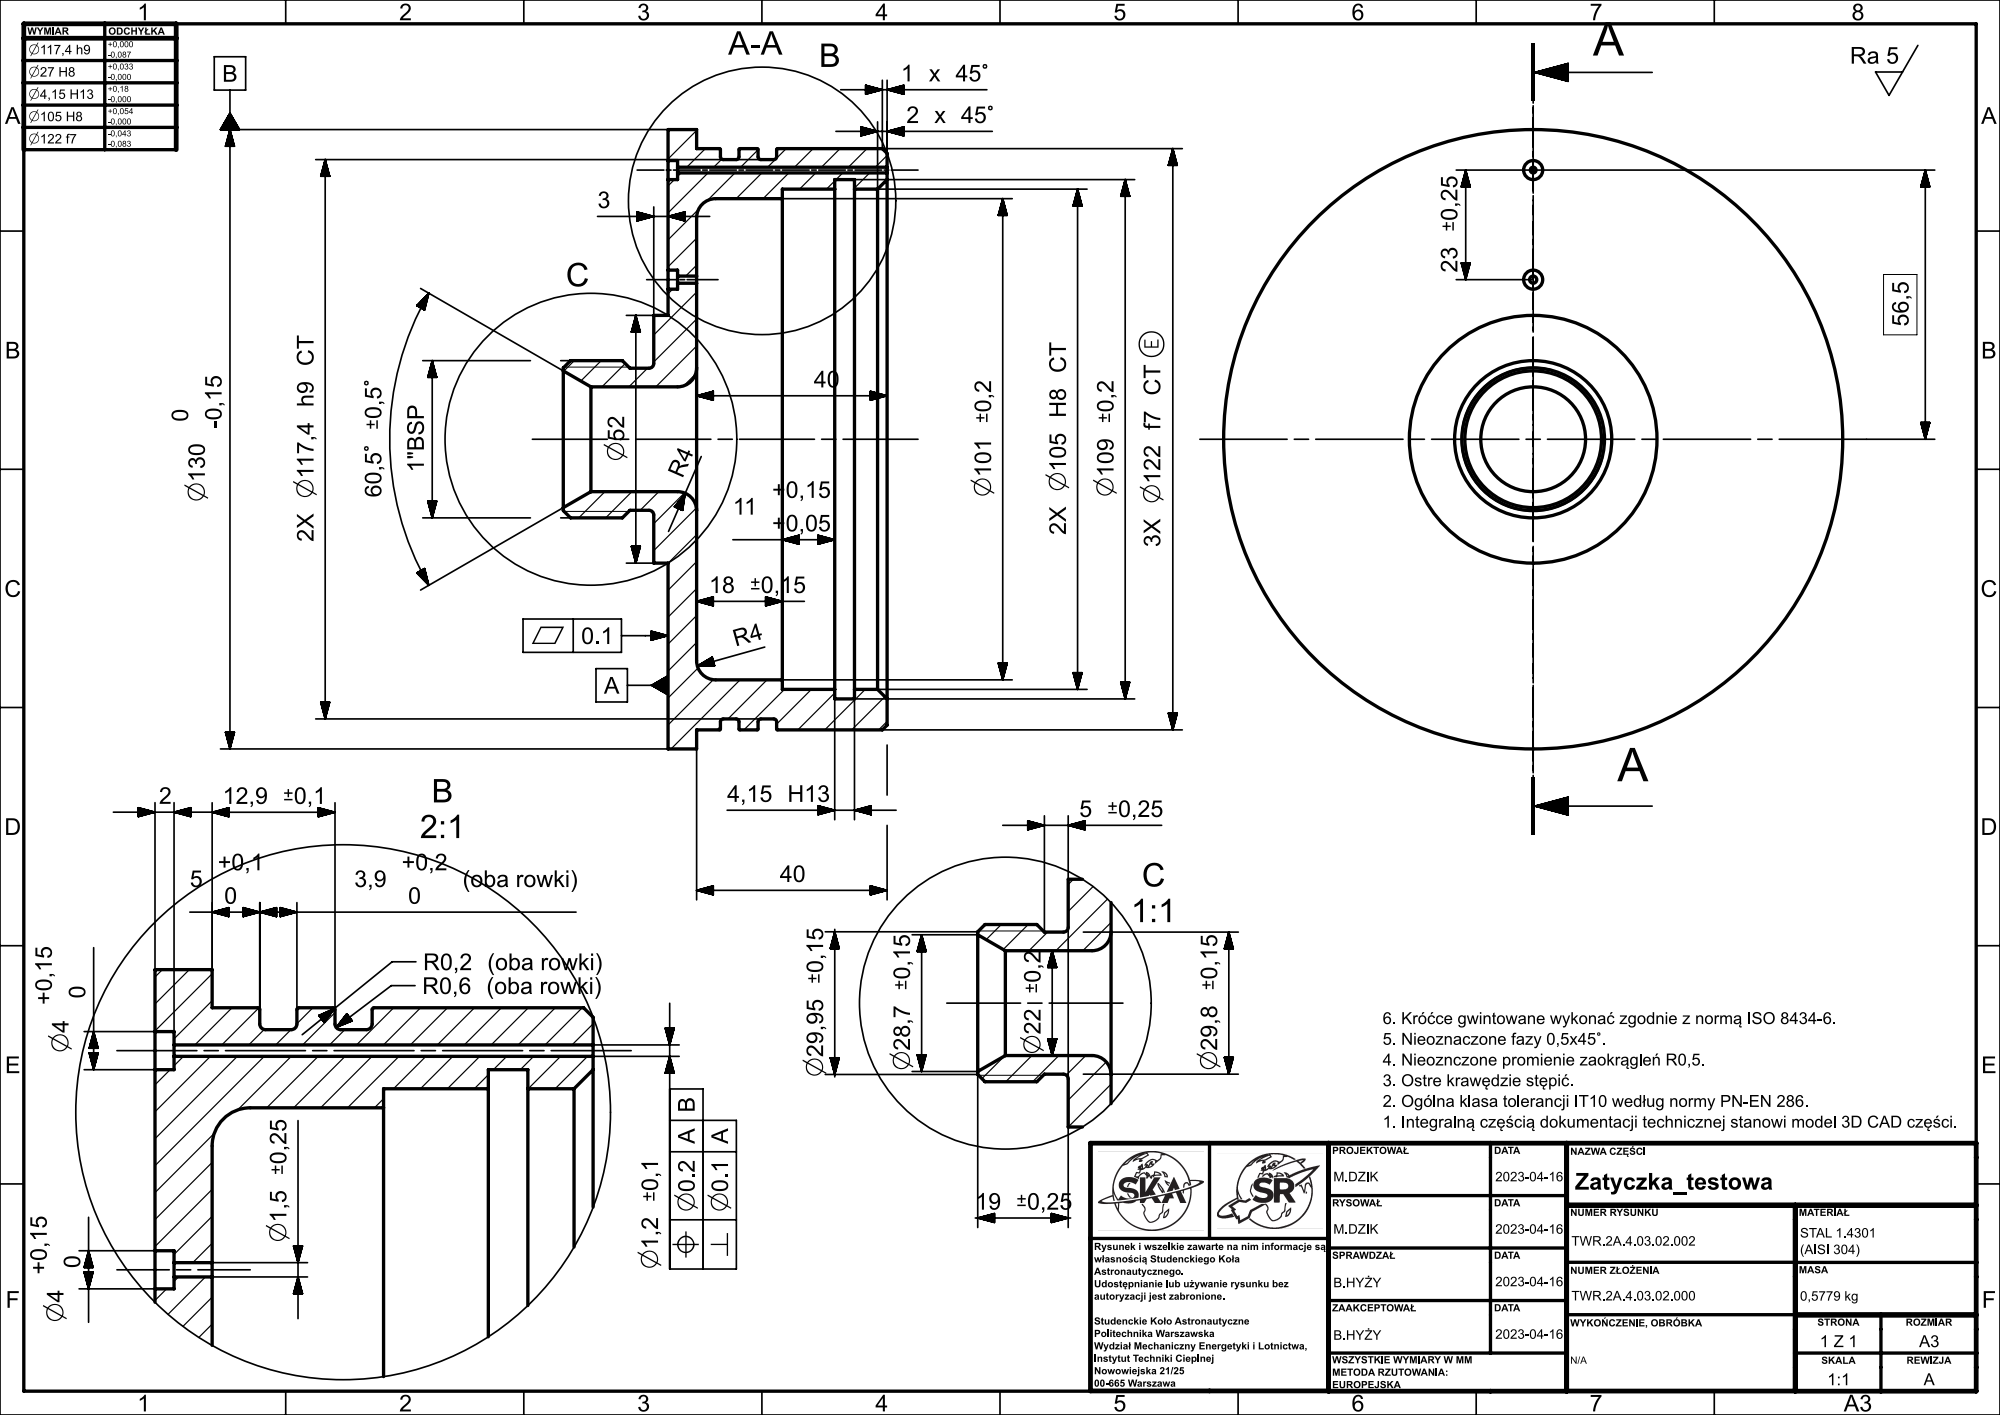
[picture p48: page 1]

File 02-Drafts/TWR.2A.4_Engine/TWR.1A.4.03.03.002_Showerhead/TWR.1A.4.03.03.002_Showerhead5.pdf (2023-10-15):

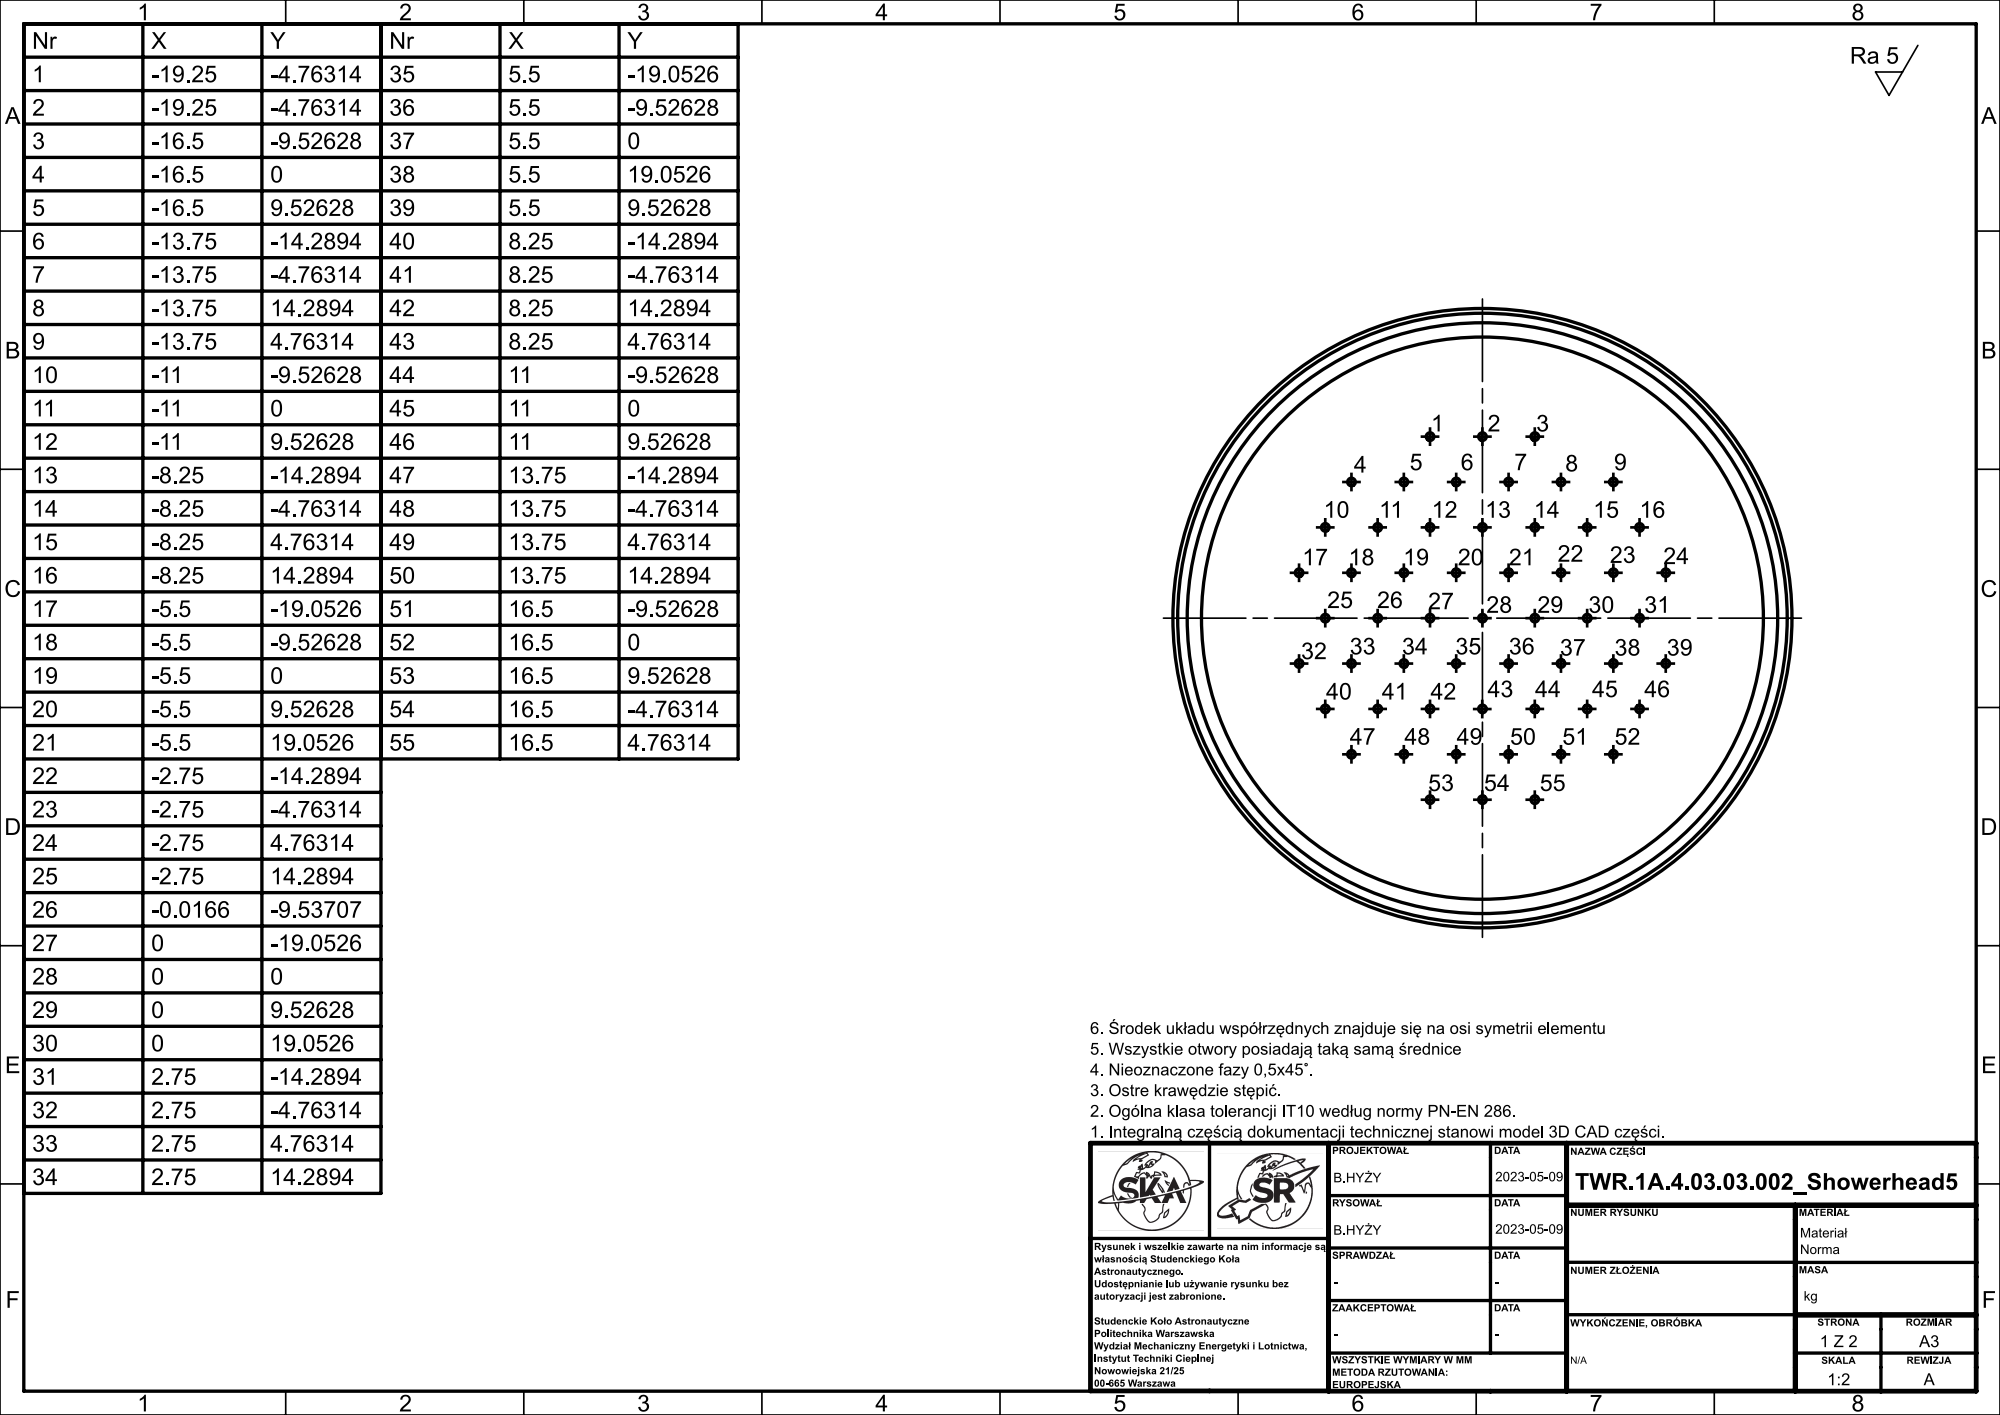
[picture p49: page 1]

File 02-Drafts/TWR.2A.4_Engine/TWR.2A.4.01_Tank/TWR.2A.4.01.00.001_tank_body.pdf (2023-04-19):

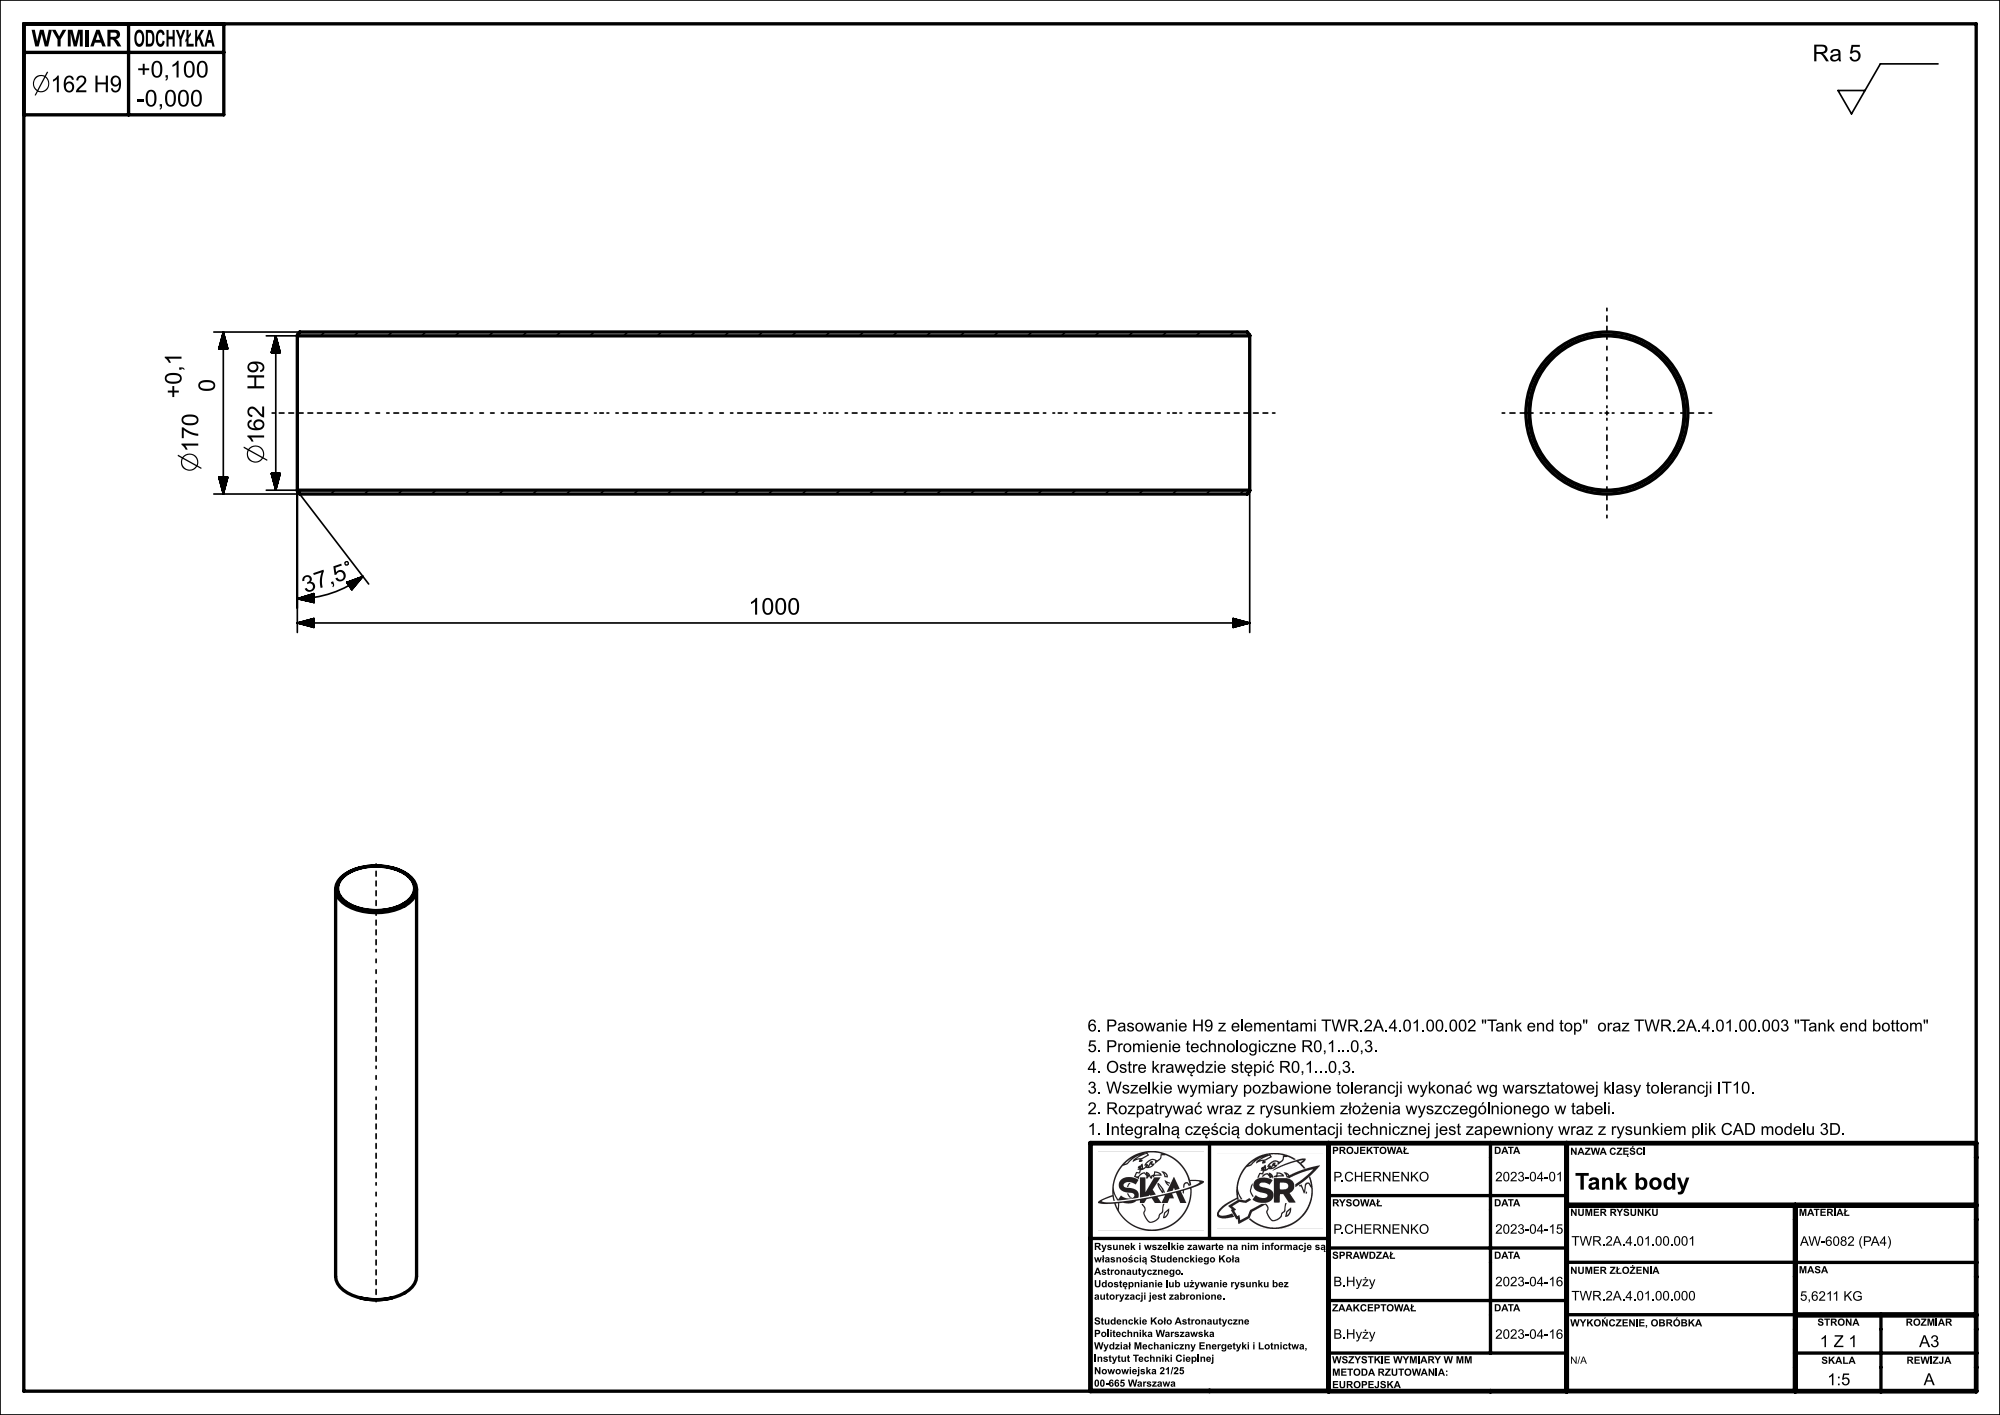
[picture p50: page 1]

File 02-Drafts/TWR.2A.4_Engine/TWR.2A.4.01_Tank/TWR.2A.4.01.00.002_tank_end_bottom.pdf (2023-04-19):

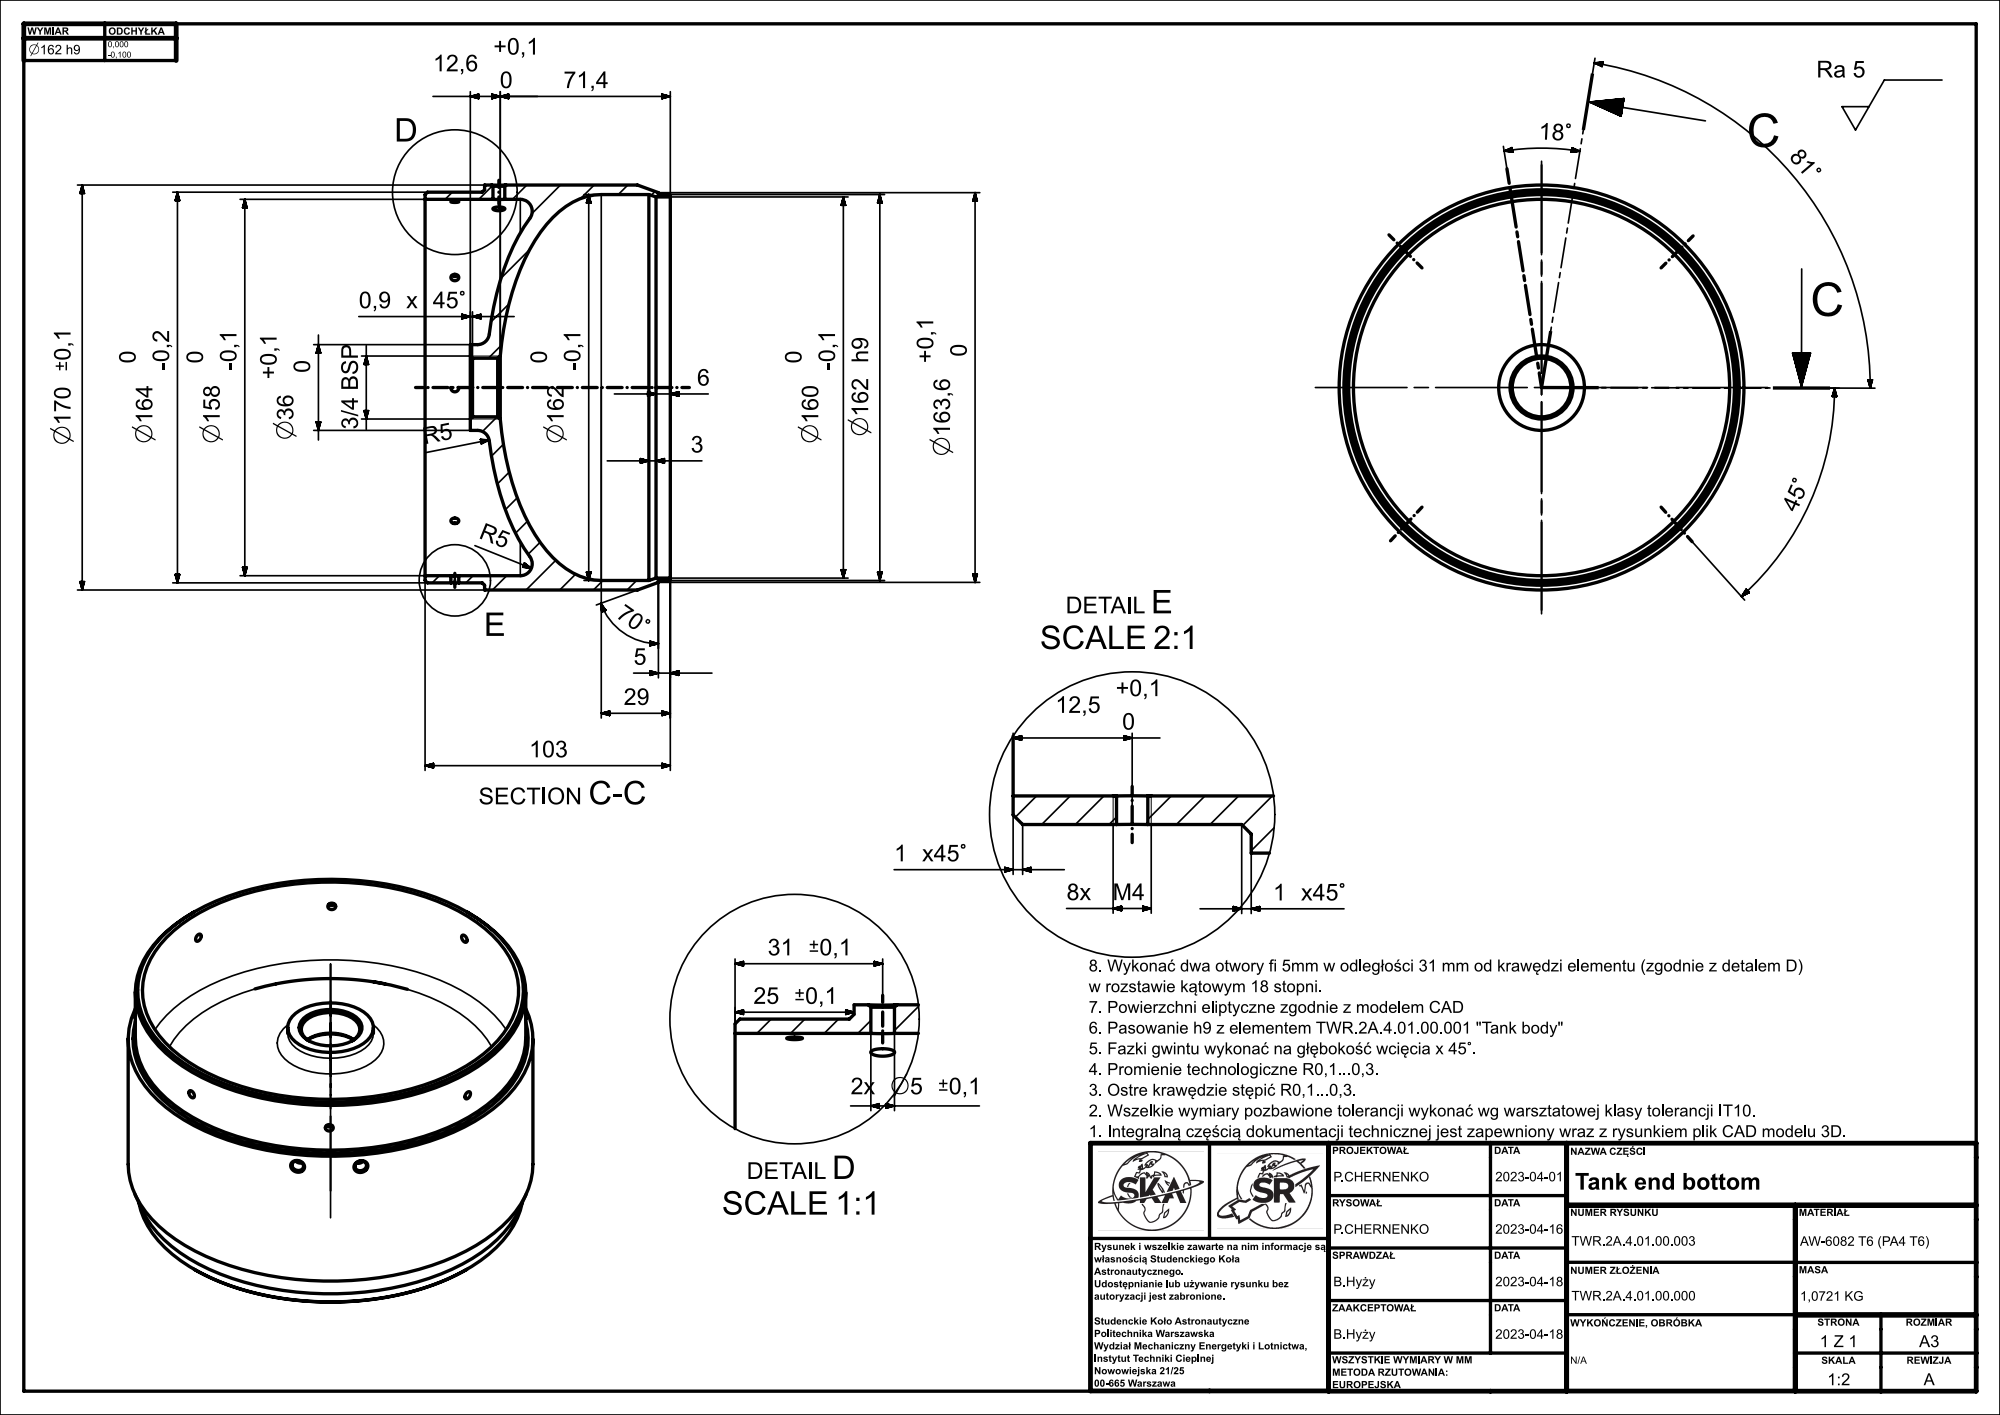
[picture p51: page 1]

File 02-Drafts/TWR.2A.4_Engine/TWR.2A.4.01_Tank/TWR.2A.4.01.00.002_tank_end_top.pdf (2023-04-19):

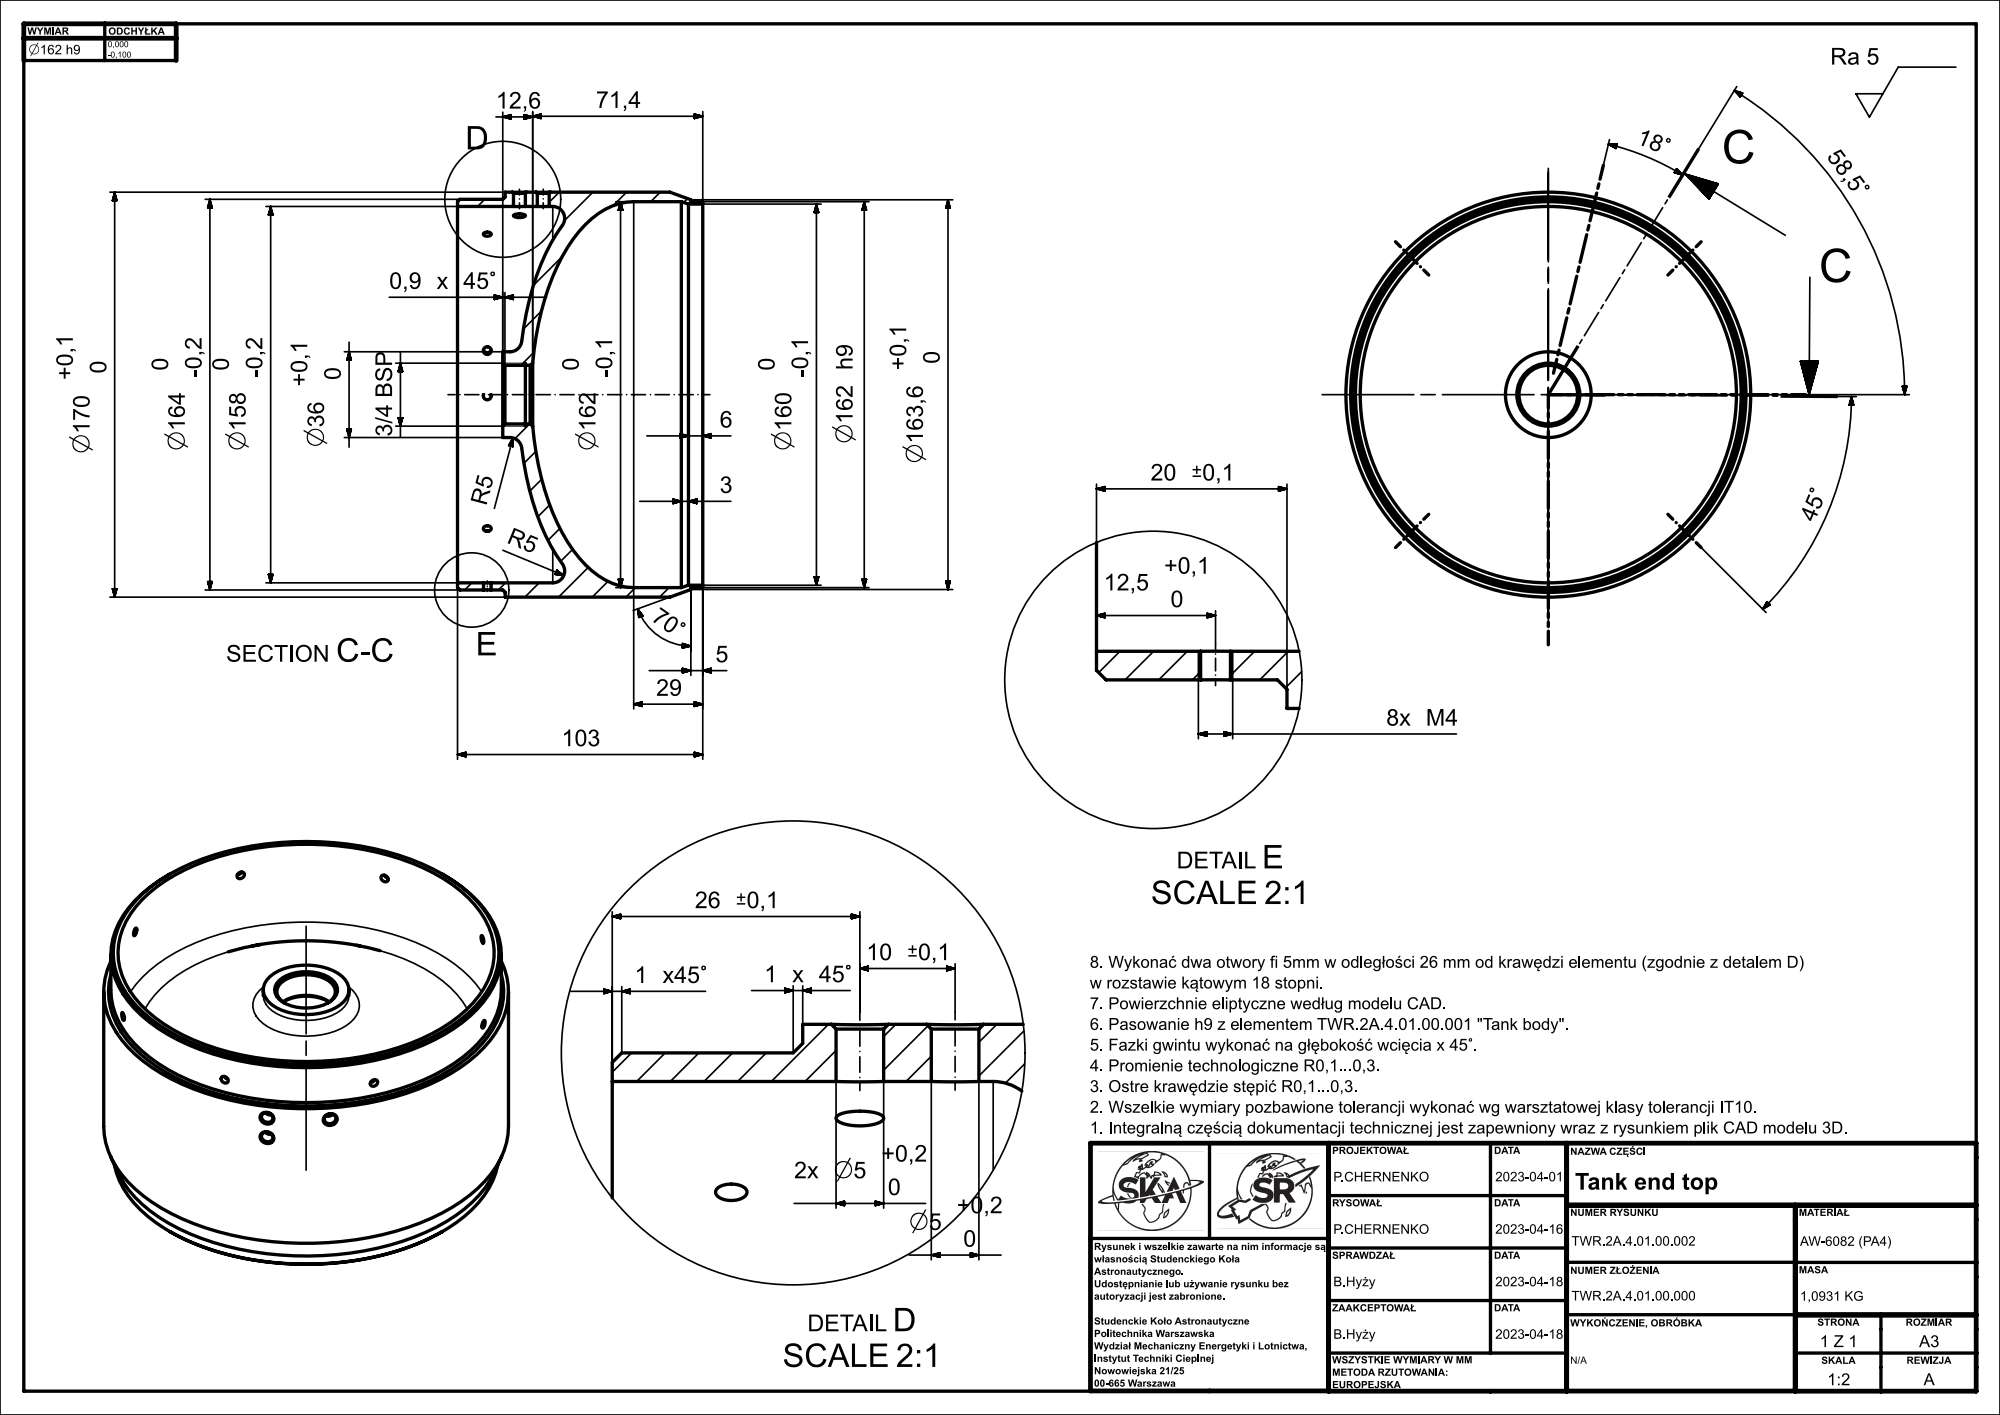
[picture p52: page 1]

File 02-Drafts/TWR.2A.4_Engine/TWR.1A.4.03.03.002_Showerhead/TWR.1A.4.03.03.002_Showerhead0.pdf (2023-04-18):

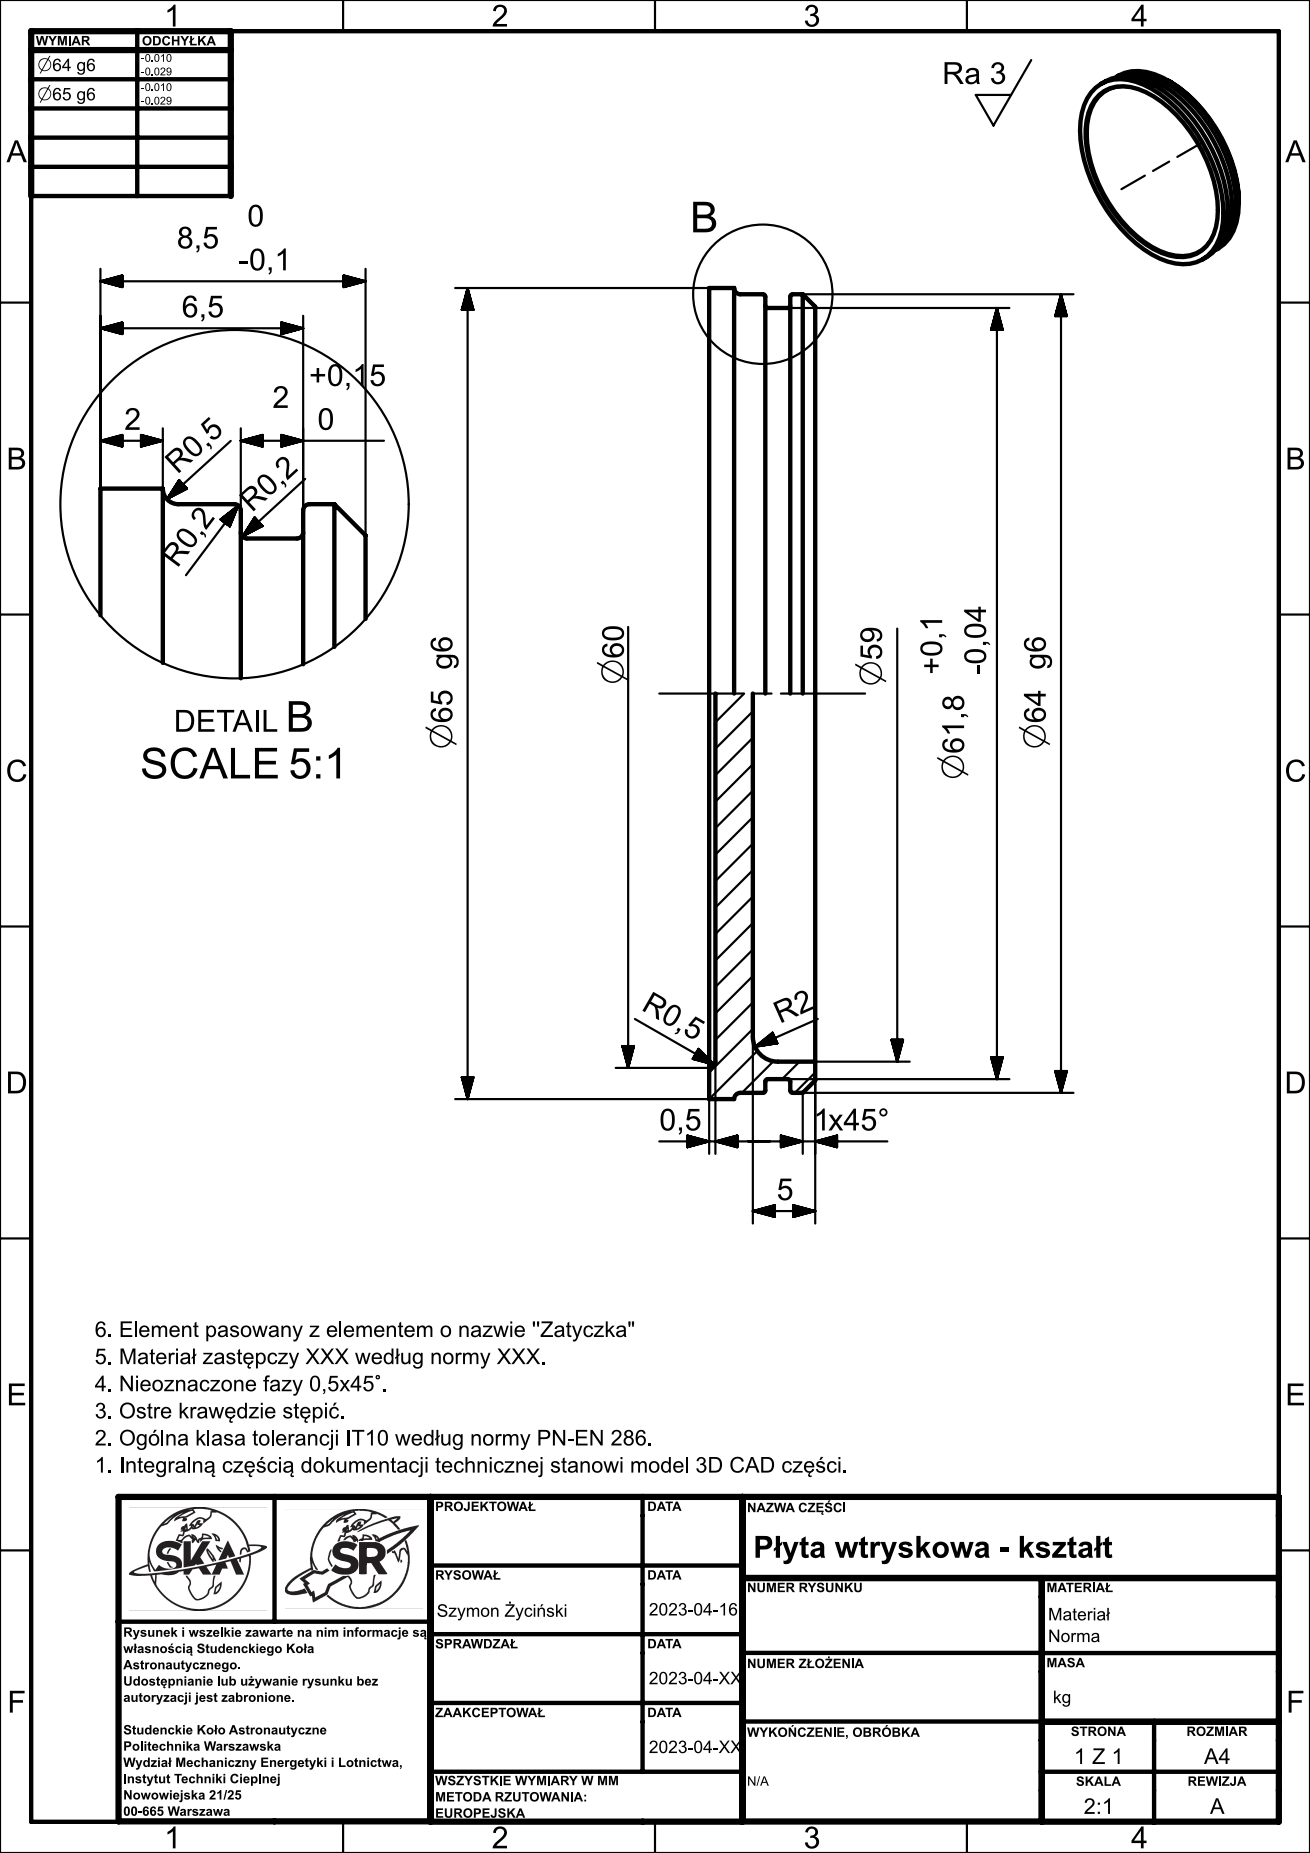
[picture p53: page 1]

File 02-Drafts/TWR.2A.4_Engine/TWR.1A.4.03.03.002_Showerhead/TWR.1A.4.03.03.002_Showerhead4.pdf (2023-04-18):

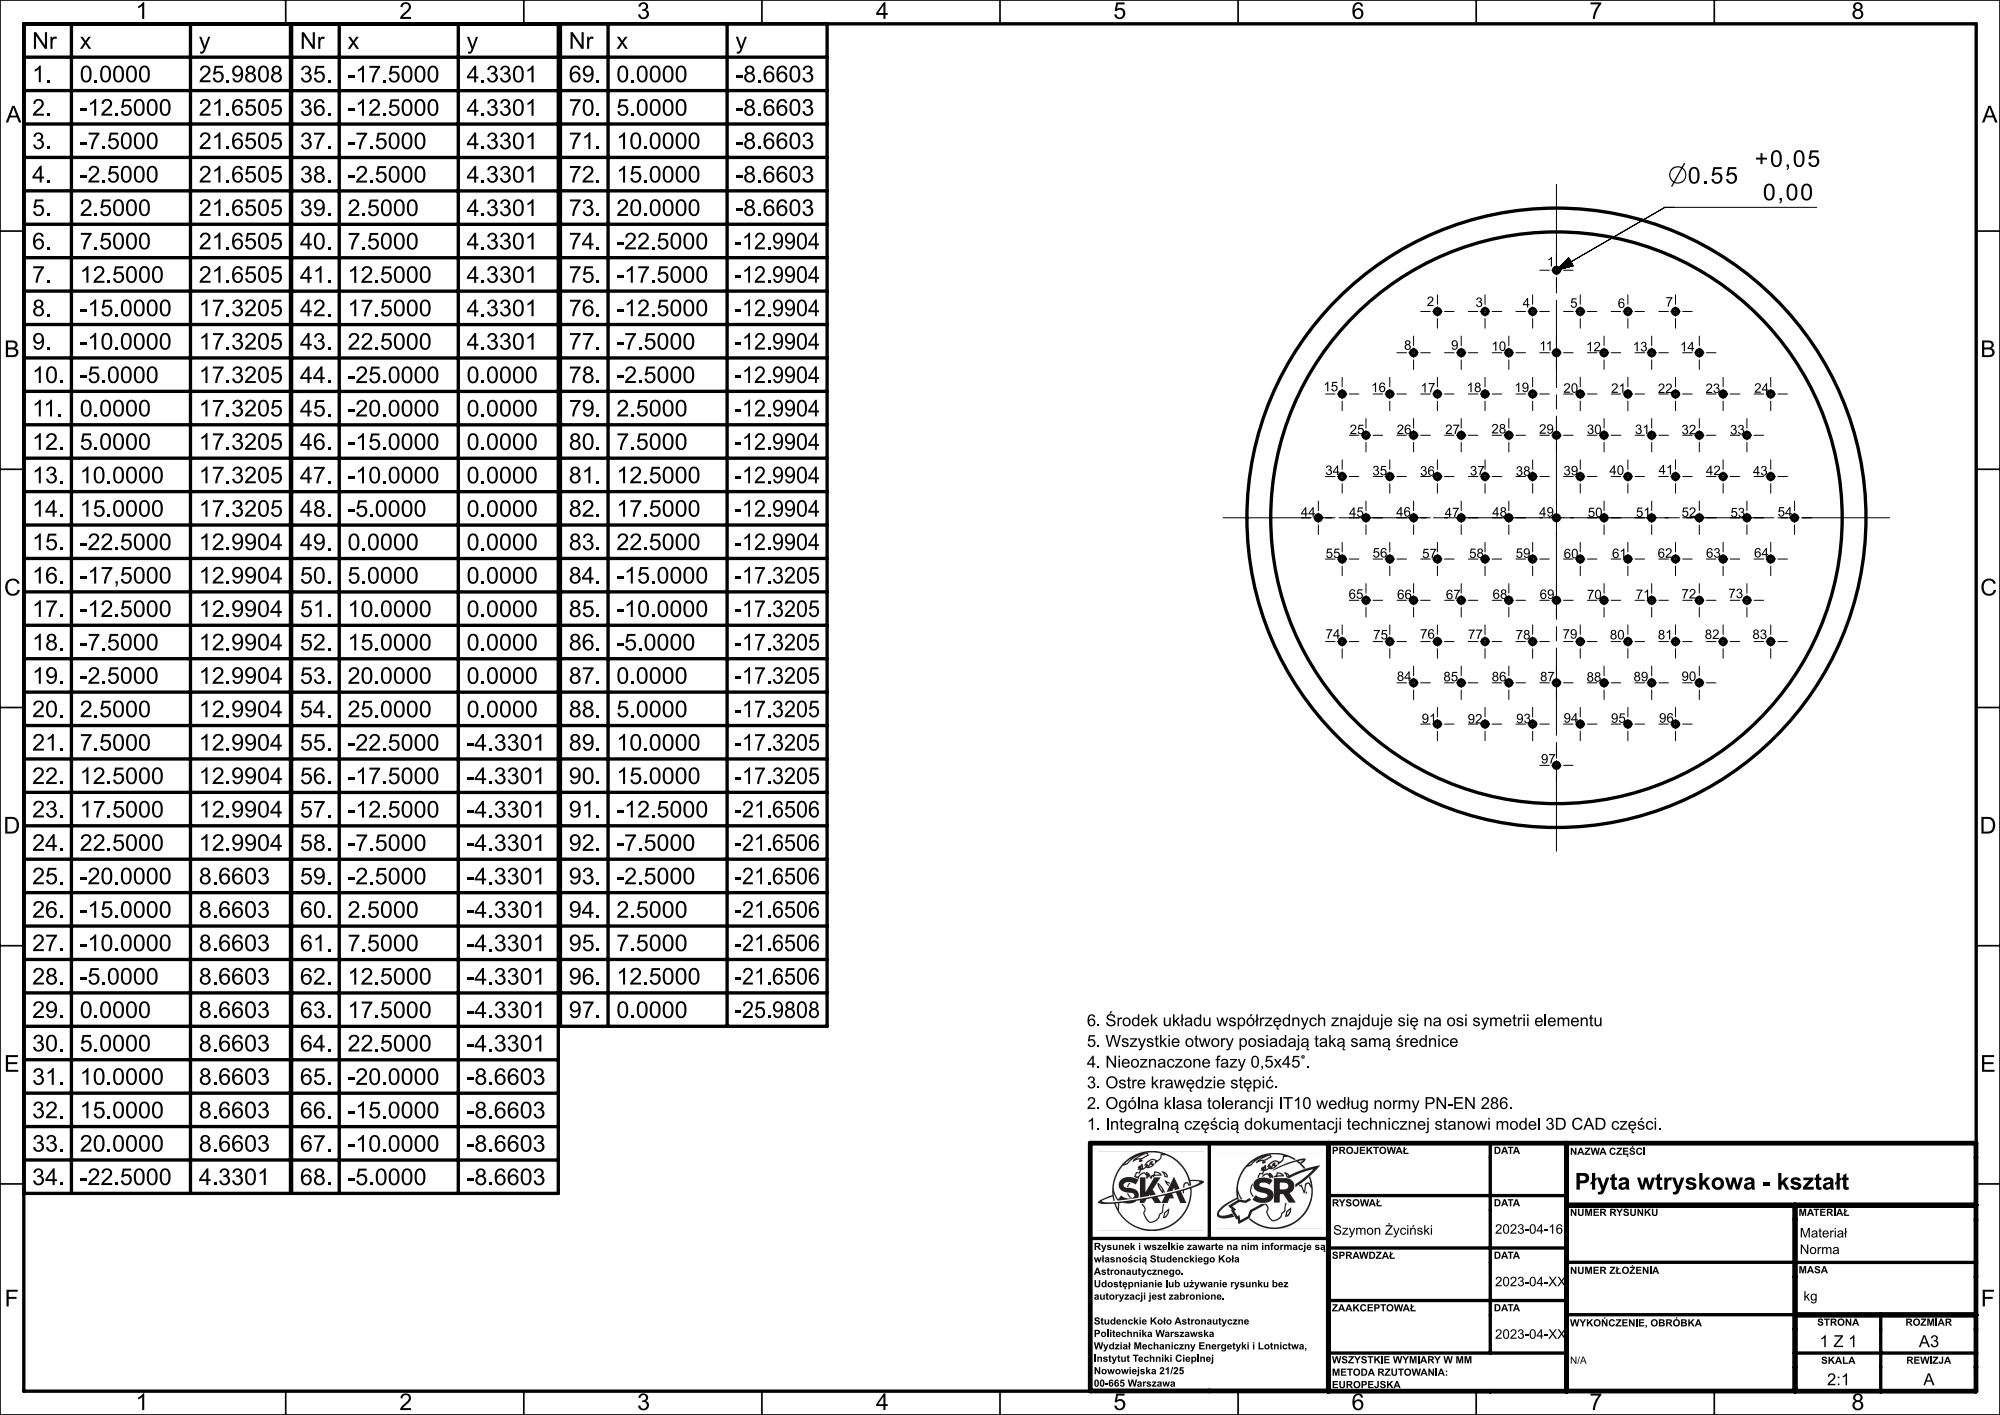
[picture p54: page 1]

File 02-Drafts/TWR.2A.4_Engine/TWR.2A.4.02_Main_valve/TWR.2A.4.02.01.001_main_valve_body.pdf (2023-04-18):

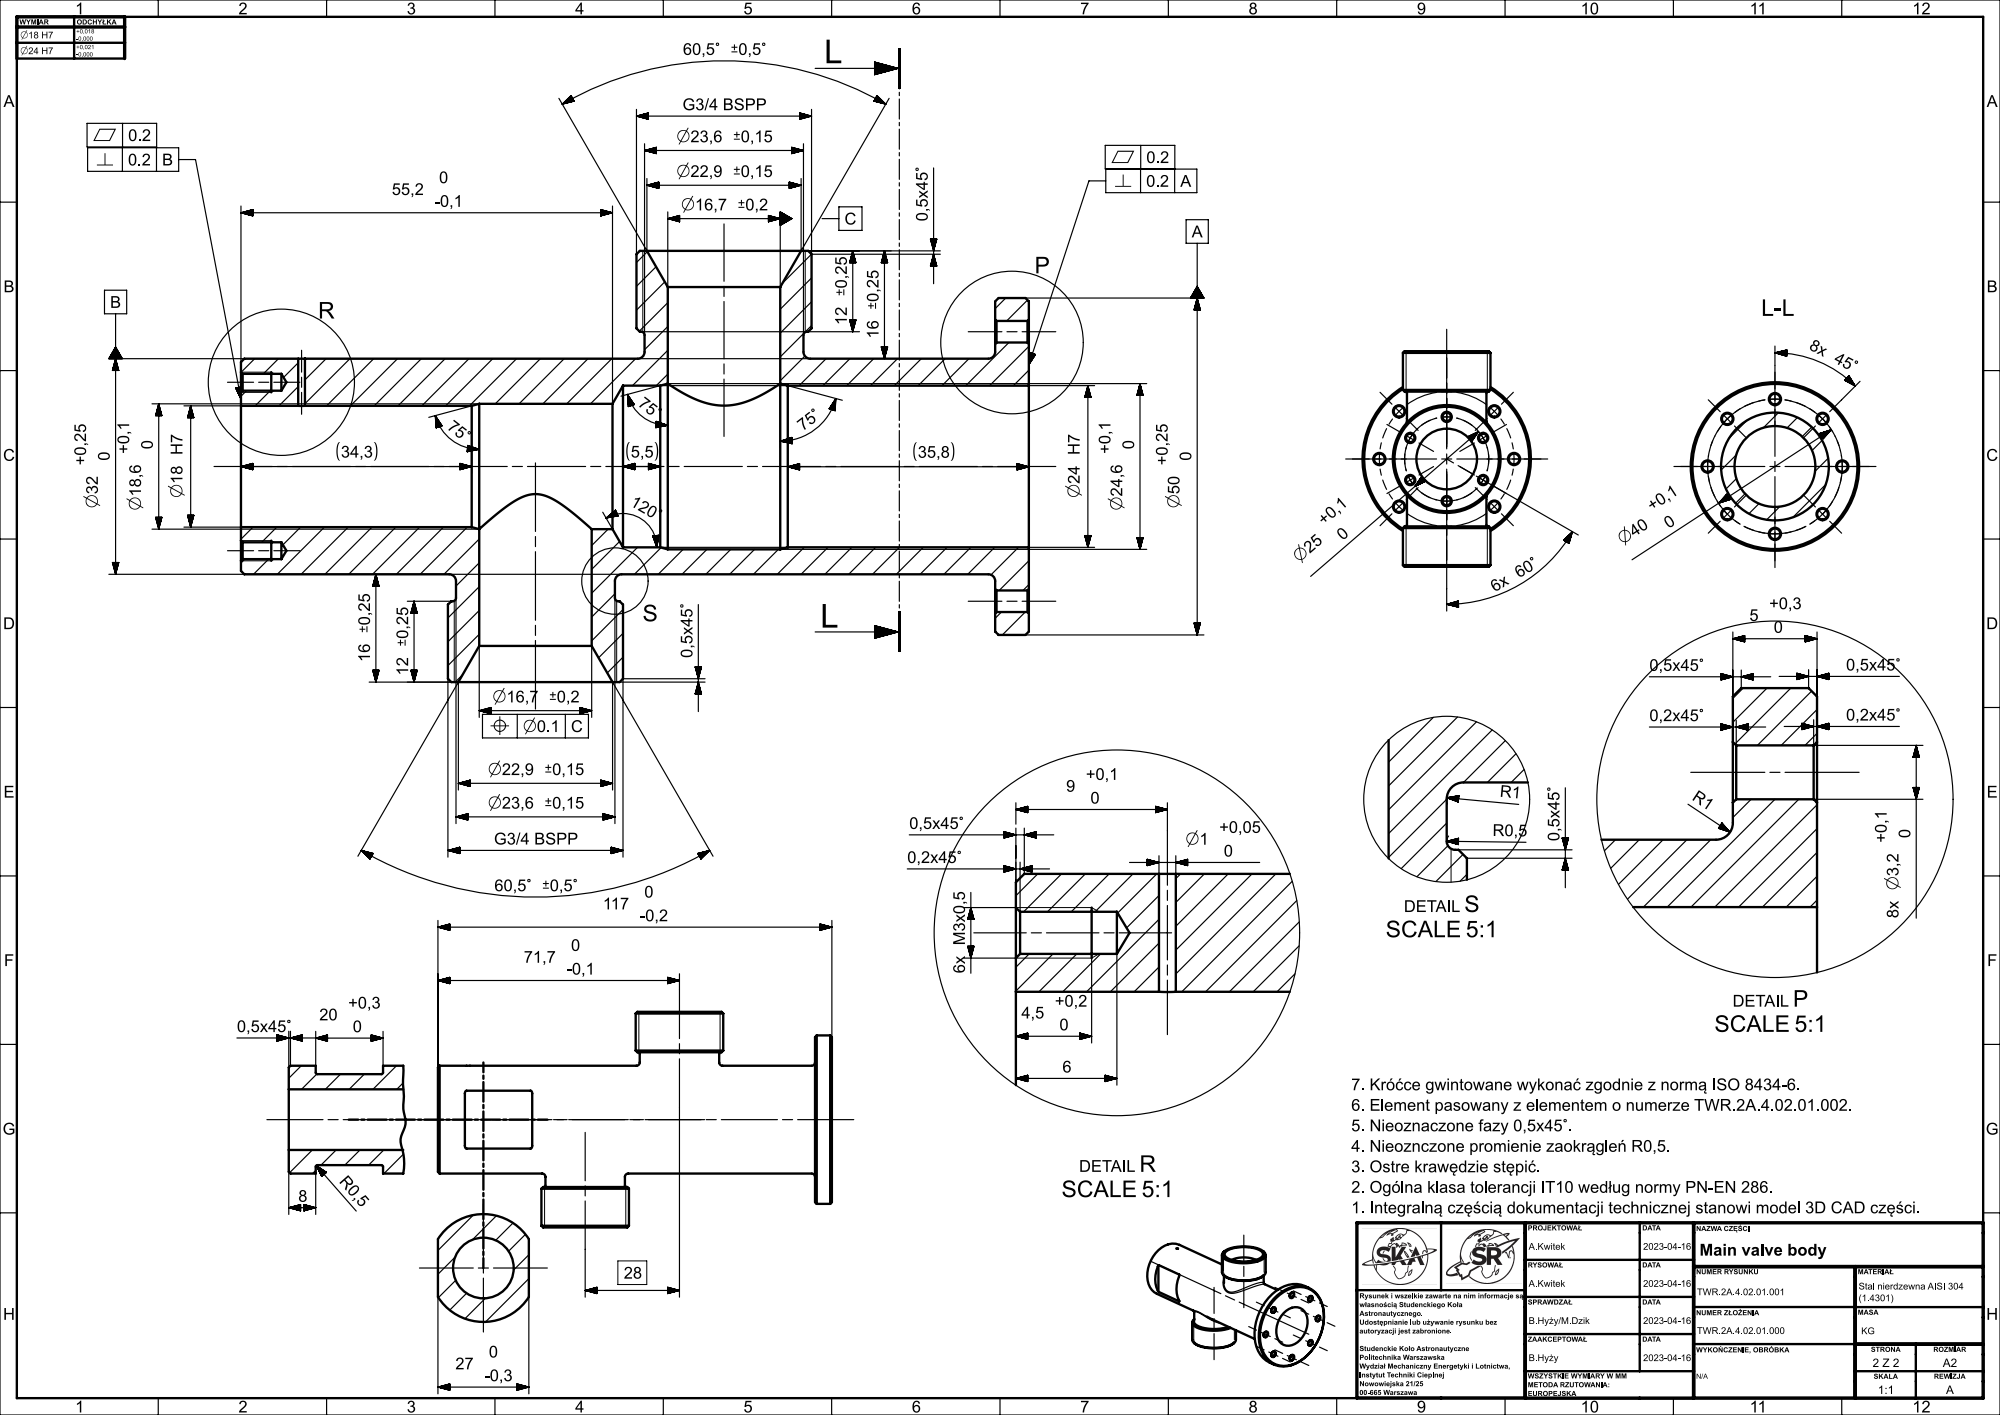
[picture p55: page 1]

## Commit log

2023-03-05 Commiting initial file for TWR2 propulsion system
    [5040500491.prt, 6062270960.prt, 6062271200.prt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]
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2023-03-05 Erasing unnecessary Grot parts and adding grain to combustion chamber
    [G.1.02.00.000_Booster.prt, G.1.02.00.002_Separator.prt, G.1.02.00.003_Compensator.prt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]
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2023-03-06 Added a joint part between the tank, and the motor chamber
    [TWR.2A.4.04.00.000_Intersection.prt]
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2023-03-07 Adding venting and measurement system assembly and intersection to propulsion system assembly
    [TWR.2.A.4.01.01.system_pomiarowo_upustowy.prt, TWR.2A.4.00.00.000_Propulsion_system.prt, TWR.2A.4.01.00.000_Tank.prt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]
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2023-03-12 Adding main valve to propulsion system assembly, adding seger rings
    [DIN_472_seeger_ring_for_bores_J130.prt, Main_valve_casing.prt, Main_valve_piston.prt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]
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2023-03-19 adding model of the plug of the small hybrid
    [A2HRMTS_assembly.prt, FOK.04.02.02.000_Ziarno_fi10-70.prt, FOK.04.02.02.000_Ziarno_fi12-70.prt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]
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2023-03-25 Added a model of the assembly of the main valve for the A2HRMTS
    [actuator_model.prt, hinge_down.prt, hinge_up.prt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]
2023-03-25 Further corrections of engine model densities
    [SS-3J-12VDC_SS-3J-12VDC_PART1.prt, TWR.2A.4.00.00.000_Propulsion_system.prt, TWR.2A.4.03.02.002_Insert.prt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]
2023-03-26 Updated assembly of the main valve for the A2HRMTS by adding a handle holder part
    [handle_holder.prt, profil2_x.prt, profil2_y.prt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]
2023-03-28 Adding grain for showerhead and swirl injector configuration
    [TWR.2A.4.03.00.000_Combustion_chamber.prt, TWR.2A.4.03.00.001_Grain.prt, TWR.2A.4.03.00.002_Grain_bates.prt]
2023-03-28 Correcting length of oxidizer tank
    [TWR.2A.4.00.00.000_Propulsion_system.prt, TWR.2A.4.01.00.000_Tank.prt, TWR.2A.4.01.00.001_tank_body.prt]
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2023-03-29 Correcting swirl element drawing
    [swirl_element_A2HRMTS.prt]
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2023-04-01 Adding new conception of connection between feeding system and combustion chamber
    [Hydraulic_coupling_AB_BSP_34_34.prt, TWR.2A.4.00.00.000_Propulsion_system.prt, TWR.2A.4.04.00.001_Intersection_C.prt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]
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2023-04-02 Adjusting plug and connector geometries, adding lamination documentation from Tucan
    [TWR.2A.4.03.02.002_Insert.prt, TWR.2A.4.03.02.003_Nozzle_insulation.prt, feeding_chamber_connector.prt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]
2023-04-03 adding hydraulic components according to Hydron technical documentation
    [TWR.2A.4.00.00.000_Propulsion_system.prt, hydron_connector_AB_34_34.prt, hydron_washer_34.prt]
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2023-04-04 Adding corrections in chamber assembly, feeding system assembly, feeding chamber connector
    [G.1.02.00.001_Insulation.prt, Hydron_BB_34_34.prt, TWR.2A.4.00.00.000_Propulsion_system.prt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]
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2023-04-06 Adding changes in chamber and feeding system, including flange main valve model
    [TWR.2A.4.00.00.000_Propulsion_system.prt, TWR.2A.4.03.00.001_Grain.prt, TWR.2A.4.03.01.000_Nozzle.prt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]
2023-04-06 fixed the model of the showerhead injector assembly
    [showerhead_assembly.prt, showerhead_injector.prt, zaplonnik_korpus1.prt]
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2023-04-07 Correcting orrifices number
    [showerhead_injector.prt]
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2023-04-07 Adding draft of closing pyrotechnic charge in main valve
    [pyro_charge_big.prt]
2023-04-09 added materials to the A2HRMTS main valve parts
    [hinge_down.prt, hinge_up.prt, katownik.prt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]
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2023-04-13 Correcting geometry after FEM analysis
    [TWR.2A.4.03.02.001_Nozzle_Body.prt, TWR.2A.4.03.02.003_Nozzle_insulation.prt]
2023-04-13 Intersection Insert
    Added correct scale to the table
    [TWR.2A.4.04.00.003_Intersection_Insert.prt]
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2023-04-15 Adding tolerance corrections to intersection insert draft
    [TWR.2A.4.04.00.003_Intersection_Insert.prt]
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2023-04-15 showerhead_assembly.prt fix
    [showerhead_assembly.prt]
2023-04-15 showerhead_assembly.prt fixes
    [showerhead_assembly.prt]
2023-04-15 showerhead fix
    [showerhead_assembly.prt]
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2023-04-15 Inital drafts
    for adaptive plate and igniter nozzle
    [dysza_zaplonnik.prt, plyta_adaptacyjna.prt, zaplonnik_korpus.prt]
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2023-04-15 Adding models and drafts of nozzle components prefabs and nozzle assembly draft
    [TWR.2A.4.03.01.000_Nozzle.prt, TWR.2A.4.03.02.001_Nozzle_Body.prt, TWR.2A.4.03.02.002_Insert.prt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]
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2023-04-16 Adding small corrections to feeding chamber connector and adding nozzle plug model with drawing
    [TWR.2A.4.03.02.006_nozzle_plug.prt, feeding_chamber_connector.prt]
2023-04-16 Further corrections to feeding chamber connector
    [feeding_chamber_connector.prt]
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2023-04-16 Adding draft corrections to main valve piston
    [main_valve_piston_small_orings.prt]
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2023-04-16 Adding adaptive plate drafts corrections
    [plyta_adaptacyjna.prt]
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2023-04-16 Adding swirl element draft corrections
    [0.02_swirl_element-TWR2.prt]
2023-04-16 adjusted geometry of the tank and added drawings
    [TWR.2A.4.01.00.000_Tank.prt, TWR.2A.4.01.00.001_tank_body.prt, TWR.2A.4.01.00.002_tank_end.prt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]
2023-04-16 Correcting draft of main valve body
    [main_valve_body.prt]
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2023-04-16 fixed intersection length
    [TWR.2A.4.00.00.000_Propulsion_system.prt, TWR.2A.4.03.00.000_Combustion_chamber.prt, TWR.2A.4.04.00.001_Intersection_A.prt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]
2023-04-16 Adding draft of tank body and modified model of top end
    [TWR.2A.4.01.00.001_tank_body.prt, TWR.2A.4.01.00.002_tank_end_top.prt]
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2023-04-16 Adding table corrections to piston draft and adding draft corrections to big charge
    [main_valve_piston_small_orings.prt, pyro_charge_big.prt]
2023-04-16 adding slider holes to the upper tank end
    [TWR.2A.4.01.00.002_tank_end_top.prt]
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2023-04-16 correcting length of intersection
    [TWR.2A.4.04.00.000_Intersection_assembly.prt, TWR.2A.4.04.00.001_Intersection_A.prt, TWR.2A.4.04.00.002_Intersection_B.prt]
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2023-04-16 holes for the slider in the lower tank end
    [TWR.2A.4.01.00.002_tank_end_bottom.prt]
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2023-04-16 adding small corrections to test plug draft
    [test_plug.prt]
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2023-04-19 Adding changes in draft and tolerances
    [TWR.2A.4.01.00.001_tank_body.prt, TWR.2A.4.01.00.002_tank_end_bottom.prt, TWR.2A.4.01.00.002_tank_end_top.prt]
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2023-05-29 fixed A2HRMTS actuator models
    [C85N25-150(0__1_0).prt, C85N25-150(0__1_0)_C8525-150_ROD.prt, C85N25-150(0__1_0)_C85N25-150(0)_BODY.prt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]
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2023-06-09 fixed valve holder model for A2HRMTS
    [C85N25-150(0__1_0).prt, actuator_holder_base.prt, actuator_holder_top.prt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]
2023-07-19 changing the holes in the main valve to fit m5 bolts
    [main_valve.prt, main_valve_body.prt, pyro_charge_big.prt]
2023-07-19 updating the drafts of main valve body and pyro_charge_big
    [TWR.2A.4.00.00.000_Propulsion_system.prt, TWR.2A.4.04.00.000_Intersection_assembly.prt, feeding_connection_assembly.prt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]
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2023-10-15 Commiting TWR1 parts drafts and initial file for test docuemnts tracking
    [TWR.1A.4.03.03.002_Showerhead3.stp, TWR.1A.4.03.03.002_Showerhead5_orrrfices_locations.xlsx, TWR2-PRP-TD-01_Propulsion_system_test_campaign.xlsx]
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2023-10-16 Changing outer diameter of the engine on model
    [TWR.2A.4.00.00.000_Propulsion_system.prt, TWR.2A.4.01.00.000_Tank-01.prt, TWR.2A.4.01.00.000_Tank.prt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]
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2023-10-19 Added a nx model of rocket airframe from Openrocket
    [TWR2_model_from_openrocket.prt]
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2023-11-12 Correcting material assignments of parts, adding bates grain to propulsion assembly
    [SS-3J-12VDC_SS-3J-12VDC_PART1.prt, SS-3J-12VDC_SS-3J-12VDC_PART3.prt, TWR.2A.4.00.00.000_Propulsion_system.prt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]
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2023-12-10 Correcting bugs in model and developing test plan documentation
    [DIN472_W105.prt, TWR.2A.4.00.00.000_Propulsion_system.prt, TWR.2A.4.03.00.000_Combustion_chamber.prt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]
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2024-01-12 Added fixed case and data for TWR2 injector's case
2024-01-18 Commiting new A2HRM simulation files after cold flow test
    [TWR2-PRP-TD-01_Propulsion_system_test_campaign.xlsx]
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2024-01-22 Correcting assembly issues
    [TWR.2A.4.03.02.000_plug_assembly.prt, TWR.2A.4.03.02.006_showerhead.prt, TWR.2A.4.03.02.007_igniter_nozzle.prt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]
2024-01-24 Adding separation to join avionics with propulsion module. Modifying part names and coloring assembly
    [TWR.2A.4.00.00.000_Propulsion_system.prt, TWR.2A.4.01.00.000_Tank-01.prt, TWR.2A.4.01.00.002_tank_end_bottom-01.prt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]
2024-01-25 Changing height of pre and post combustion chamber
    [G.1.02.00.001_Insulation.prt, G.1.02.01.000_Casing.prt, G.1.02.01.002_Laminate.prt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]
2024-01-27 Adding distance insulation models, modifying combustion chamber length, updating grains drafts, general work on test documentation
    [G.1.02.00.001_Insulation.prt, G.1.02.01.000_Casing.prt, G.1.02.01.002_Laminate.prt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]
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2024-02-04 Adding tooling and checklist for pressure proof tests of combustion chamber
    [TG.5.02.00.001_Closure_hydro_plug_2.prt]
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
